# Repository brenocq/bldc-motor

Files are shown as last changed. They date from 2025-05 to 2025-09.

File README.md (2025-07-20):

<div align="center">
  
</div>

# BLDC Motor Controller

> [!NOTE]
> This project is currently in active development. Features and documentation are subject to change.

## Table of Contents
- [Project Overview](#project-overview)
- [Folder Structure](#folder-structure)
- [Mechanical](#mechanical)
- [Electronics](#electronics)
  - [MCU PCB (Top Board)](#mcu-pcb-top-board)
  - [Power PCB (Bottom Board)](#power-pcb-bottom-board)
- [Firmware](#firmware)
- [Simulation](#simulation)
- [Results](#results)
- [License](#license)

---

## Project Overview

This project aims to develop a **high-precision Brushless DC (BLDC) motor controller** from scratch, covering both hardware and firmware aspects. The controller is designed for advanced motor control applications, leveraging a powerful STM32 microcontroller, a dedicated motor driver IC, and comprehensive sensing capabilities for precise operation and rotor position estimation.

The core of the system is a custom two-board stack: an MCU board housing the main control logic and a power board managing motor drive and sensing.

## Folder Structure

The project is organized into logical directories to enhance maintainability and readability:

* `simulation/`: Contains code and files related to motor control simulation.
* `mechanical/`: Houses all mechanical design files (CAD models, part designs).
* `electronics/`: Stores KiCad project files for both the MCU and Power PCBs, including schematics and PCB layouts.
* `firmware/`: Contains all the embedded software for the STM32 microcontroller.
* `controller/`: Specific implementations of motor control algorithms (trapezoidal, FOC).
* `common/`: Shared utilities and communication definitions across different parts of the project.

---

## Mechanical

The mechanical aspects of this project are centered around integrating the custom electronics with an off-the-shelf **EM3215 BLDC motor**. It's important to note that, for this specific project, the **motor's original windings are being utilized**, and there are no plans to re-wrap the wire around the coils. The `mechanical` folder contains various CAD files (FreeCAD) for components like the rotor adapter, chassis, and PCB cutouts, ensuring a perfect fit and robust assembly.

<div align="center">
  
</div>

---

## Electronics

The electronics consist of two interconnected custom-designed Printed Circuit Boards (PCBs), designed using **KiCad**. Both boards are **4-layer designs** to facilitate efficient signal routing and power integrity. A **Molex PCB stack connector** is used to establish a robust electrical connection between the MCU and Power PCBs.

### MCU PCB (Top Board)

The top PCB serves as the brain of the controller, housing the main microcontroller and various sensors and interfaces for user interaction and precise feedback.

| Top Layer | Layer 1 | Layer 2 | Bottom Layer | 3D Top View | 3D Bottom View |
| :---: | :---: | :---: | :---: | :---: | :---: |
| Layer 1 (Top Copper) | Layer 2 (Inner 1) | Layer 3 (Inner 2) | Layer 4 (Bottom Copper) | 3D Top View | 3D Bottom View |

**MCU PCB Key Components:**
- **STM32F4 Microcontroller:** The central processing unit for control algorithms, sensor data acquisition, and communication.
- **AS5048A Angle Position Encoder:** Provides 14-bit absolute rotor position feedback for precise commutation and control.
- **SK6805 LED Ring:** A customizable visual indicator for status and debugging.
- **Reset Button:** For convenient system resets.
- **ISM330DHCX IMU (Inertial Measurement Unit):** Provides acceleration and angular velocity data, useful for advanced motion control or system stabilization.

**MCU PCB v1.0 Release Package:**
- **[KiCad Project](https://github.com/brenocq/bldc-motor/tree/electronics/v1.0/electronics/BLDCM-MCU)**
- **[Schematic (PDF)](https://github.com/brenocq/bldc-motor/blob/electronics/v1.0/electronics/BLDCM-MCU/BLDCM-MCU.pdf)**
- **[Interactive BOM (HTML)](https://brenocq.s3.us-east-1.amazonaws.com/BLDCM/BLDCM-MCU-BOM-v1.0.html)**
- **[Gerbers (ZIP)](https://github.com/brenocq/bldc-motor/releases/download/electronics%2Fv1.0/BLDCM-MCU-v1.0-gerber.zip)**

### Power PCB (Bottom Board)

The bottom PCB handles the high-current motor driving functions and essential power monitoring.

| Top Layer | Layer 1 | Layer 2 | Bottom Layer | 3D Top View | 3D Bottom View |
| :---: | :---: | :---: | :---: | :---: | :---: |
| Power PCB Layer 1 (Top Copper) | Power PCB Layer 2 (Inner 1) | Power PCB Layer 3 (Inner 2) | Power PCB Layer 4 (Bottom Copper) | Power PCB 3D Top View | Power PCB 3D Bottom View |

**Power PCB Key Components:**
- **TMC6300 Motor Driver:** A 3-phase motor driver that translates the MCU's PWM and control signals into high-current outputs for the motor phases.
- **TCAN1462 CAN Transceiver:** Enables robust CAN FD communication for daisy-chaining motors in series.
- **J-Link Connector:** Provides easy SWD debugging and programming for the STM32 microcontroller.
- **USB Connector:** Facilitates direct USB Full-Speed communication for data logging, control, and power input.
- **Micro-Lock Plus Connectors:** Robust 4-pin Molex connectors that provide a vibration-resistant link for power delivery and CAN bus communications.
- **Voltage Sensors (x4):** One monitors the DC bus voltage, while three dedicated sensors measure filtered phase voltages for safe operation and FOC.
- **INA240 Current Sensors (x3):** Three precision analog-output current sensors enable high-speed, accurate phase current measurement for FOC.

**Power PCB v1.0 Release Package:**
- **[KiCad Project](https://github.com/brenocq/bldc-motor/tree/electronics/v1.0/electronics/BLDCM-Power)**
- **[Schematic (PDF)](https://github.com/brenocq/bldc-motor/blob/electronics/v1.0/electronics/BLDCM-Power/BLDCM-Power.pdf)**
- **[Interactive BOM (HTML)](https://brenocq.s3.us-east-1.amazonaws.com/BLDCM/BLDCM-Power-BOM-v1.0.html)**
- **[Gerbers (ZIP)](https://github.com/brenocq/bldc-motor/releases/download/electronics%2Fv1.0/BLDCM-Power-v1.0-gerber.zip)**

---

## Firmware

The firmware, developed for the **STM32F4** microcontroller, is the intelligence behind the motor control. It includes:

* **Low-level Peripheral Drivers:** Custom drivers for ADC, timers, GPIO, SPI, I2C, UART, USB, and DMA to efficiently manage hardware resources.
* **Motor Control Algorithms:** Implementation of both **trapezoidal** and **Field-Oriented Control (FOC)** algorithms, located in the `controller` directory, to provide flexible and high-performance motor driving capabilities.
* **Sensor Integration:** Code to interface with the MT6701 encoder, INA239-Q1 current sensors, voltage sensor, and ISM330DHCX IMU for comprehensive feedback.
* **System Utilities:** Logging, error handling, and platform-specific configurations for the STM32 environment.

_The firmware architecture and design decisions will be documented in the future._

---

## Simulation

The `simulation` directory contains resources for simulating the BLDC motor system and visualizing the sensor data in real time. This allows for testing and validating control algorithms and system behavior in a virtual environment before deployment on the hardware. The `bldc.atta` file can be opened with [Atta](https://github.com/brenocq/atta), and it implements a basic motor model simulation and plotting of sensor data.

_Instructions on how to run the BLDCM simulation with [Atta](https://github.com/brenocq/atta) will be added in the future_

---

## Results

Below are some pictures/videos taken during the development. The controller design and calibration procedures will be explained in depth in the future :)

https://github.com/user-attachments/assets/e86b0316-7ecf-4e15-9d3b-c0315d690438

<div align="center">
  
  
  
</div>

## License
This project is licensed under the MIT License - check [LICENSE](LICENSE) for details.

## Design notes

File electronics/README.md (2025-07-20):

# BLDCM Electronics
These KiCad projects were made with KiCad 9.0, make sure to use the same version or a newer one.

The schematic PDFs are available in `BLDCM-Power/BLDCM-Power.pdf` and `BLDCM-MCU/BLDCM-MCU.pdf`. The Gerber files and interactive BOM can be found in the release section of the repository.

> [!IMPORTANT]
> This project depends on the [BrenoCQ KiCad library](https://github.com/brenocq/brenocq-kicad-library), included as a Git submodule. To ensure all symbols, footprints, and 3D models are available, you must initialize the submodules:
>
> ```bash
> git submodule update --init --recursive
> ```

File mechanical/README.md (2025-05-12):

# BLDC Motor - Mechanical

The 3D models were designed using FreeCAD 1.0.0, Git Large File Storage (LFS) was enabled so we can store the `.FCStd` files in this repository without considerably growing the repository size.

### BOM
- Three-phase motor OT-EM3215D2450Y1R - [Sparkfun](https://www.sparkfun.com/three-phase-brushless-gimbal-stabilizer-motor.html)

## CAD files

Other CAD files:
mechanical/BLDCM.FCStd
mechanical/BLDCM_Chassis.FCStd
mechanical/BLDCM_PCB_MCU.FCStd
mechanical/BLDCM_Rotor_Adapter.FCStd
mechanical/parts/Motor_EM3215.FCStd
mechanical/BLDCM_PCB_Power.FCStd
mechanical/parts/Test_HeatSet_Hole.FCStd
mechanical/parts/HeatSet_M1.6_3MM.FCStd
mechanical/parts/Screw_CS_5MM.FCStd
mechanical/parts/Flat_Washer_M1.6.FCStd
mechanical/parts/Screw_P_8MM.FCStd

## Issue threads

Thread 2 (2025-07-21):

[Bug] v1.0 PCB Issues & Revisions

brenocq, 2025-07-21:
**Overview**
This issue serves as a master list to track all identified bugs, design flaws, and potential improvements for the [v1.0 MCU and Power PCBs](https://github.com/brenocq/bldc-motor/releases/tag/electronics%2Fv1.0). The goal is to consolidate all feedback from testing and board bring-up to inform the design of the v1.1 revision.

brenocq, 2025-08-02:
It would be better to cover vias with solder mask if they are close to pads of different nets (to avoid solder bridges between different nets)

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

brenocq, 2025-08-05:
## BLDCM-MCU v1.0 bring-up checklist
- [x] Solder all components
- [x] Visual inspection (solder bridges, alignment)
- [ ] Verify orientation of all ICs
- [ ] Clean board with IPA
- [ ] Continuity check for all adjacent pins
- [ ] Check resistance between all power rails (3.3V, 5V) and GND
- [ ] Apply current-limited Power @ 50mA
- [ ] Verify 3.3V power rail
- [ ] Connect ST-Link and verify MCU detection
- [ ] Flash simple firmware

brenocq, 2025-08-16:
## Firmware v1.0 bring-up checklist
- [ ] Finalize pinout assignments
- [ ] Establish real-time logging via SWO
- [ ] Test UART interface
- [ ] Verify the TMC6300 motor driver functionality.
- [ ] Implement and test USB interface
- [ ] Validate INA240A1 current measurements
- [ ] Validate voltage measurements
- [ ] Verify data acquisition from the ISM330DHCX IMU
- [ ] Implement and validate the AS5048A encoder driver
- [ ] Validate the SK6805 RGB LED driver

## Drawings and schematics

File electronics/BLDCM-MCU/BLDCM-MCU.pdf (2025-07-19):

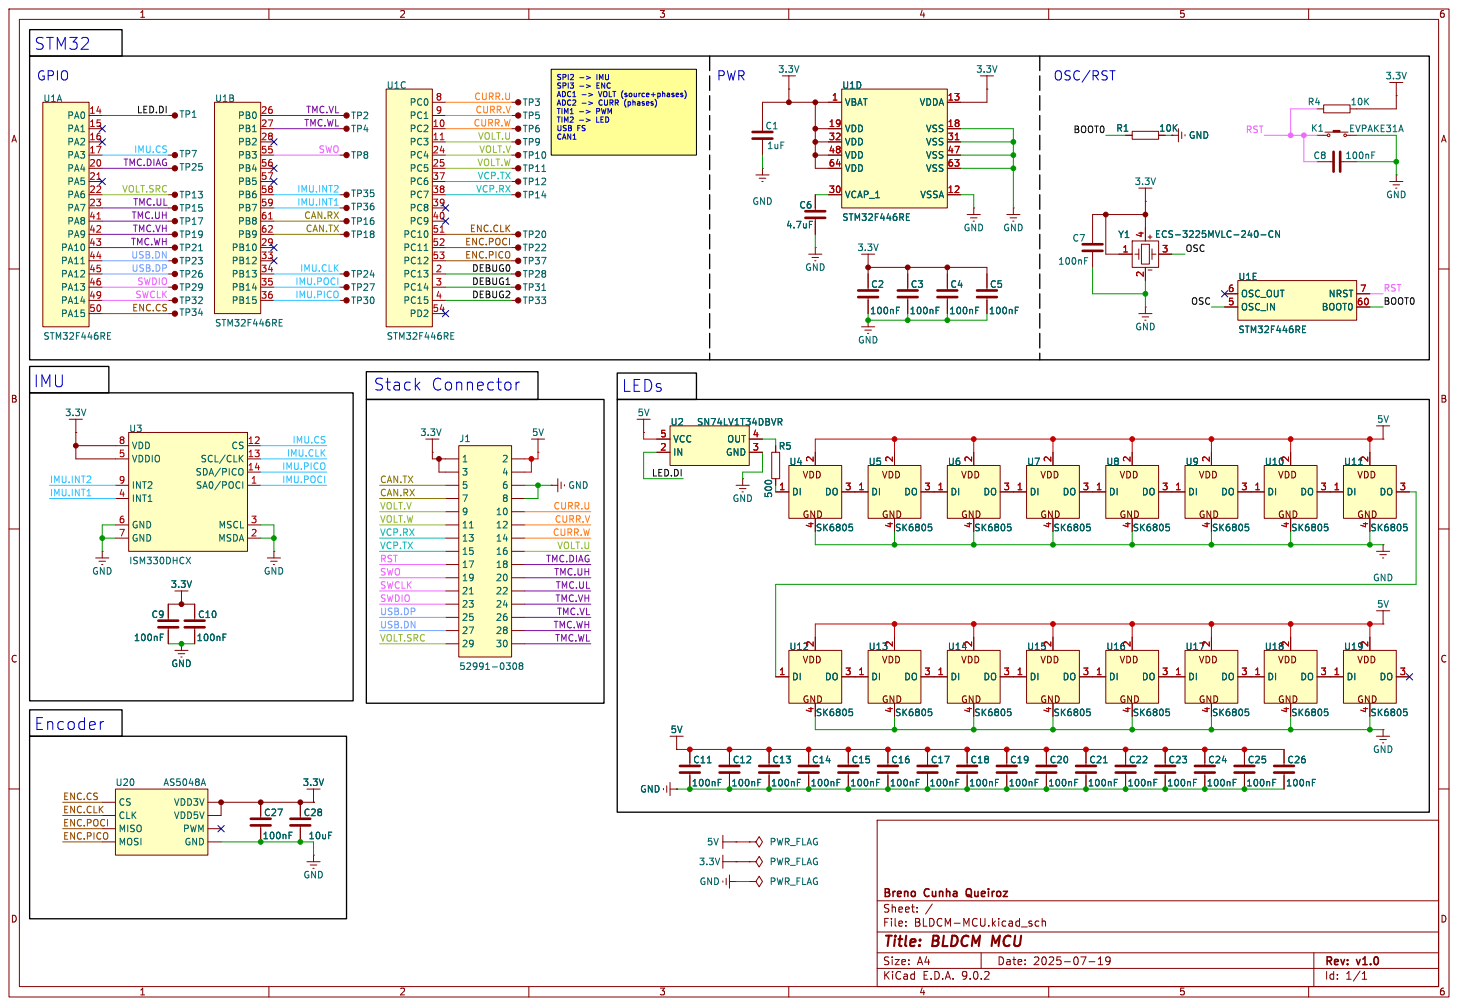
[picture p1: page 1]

USB FS CAN1 Stack Connector

VOLT.SRC
TMC.UH
TMC.VH
DEBUG2 TMC.WH
USB.DN
RST BOOT0 ENC.CS USB.DP
SWDIO

IMU.INT1
ENC.POCI CAN.RX
DEBUG0 DEBUG1 CAN.TX

CAN.TX RST CAN.RX

TMC.WL TMC.WH

File: BLDCM-MCU.kicad_sch Sheet: / Breno Cunha Queiroz

Id: 1/1 Title: BLDCM MCU

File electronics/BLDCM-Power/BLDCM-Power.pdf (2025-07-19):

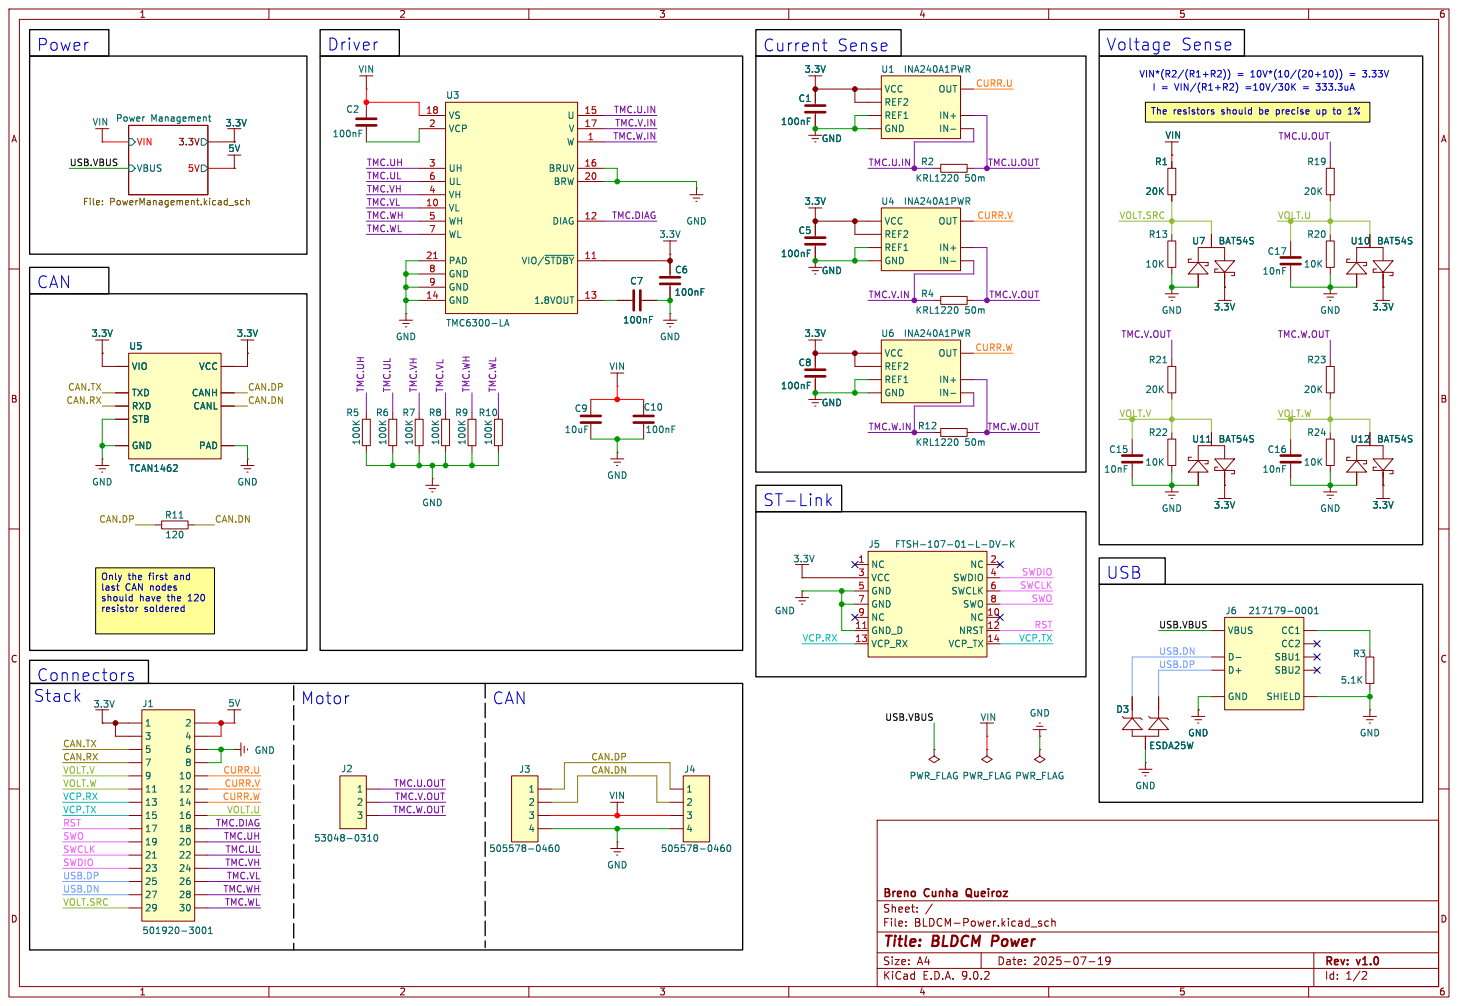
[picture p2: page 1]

TMC.UL TMC.VL TMC.VH
TMC.VH

TMC.WL TMC.WH

CAN.DP CAN.DN

Only the first and
last CAN nodes
should have the 120

USB.VBUS USB.DP USB.DN

Stack
CAN.RX CAN.TX USB.DP

Id: 1/2 Title: BLDCM Power File: BLDCM-Power.kicad_sch Sheet: / Breno Cunha Queiroz

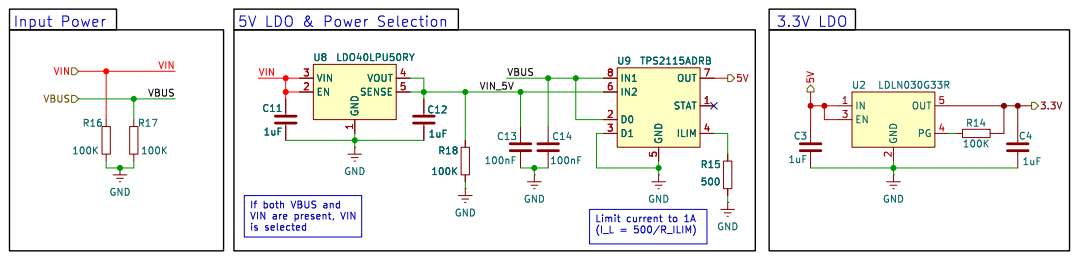
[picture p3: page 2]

If both VBUS and VIN are present, VIN

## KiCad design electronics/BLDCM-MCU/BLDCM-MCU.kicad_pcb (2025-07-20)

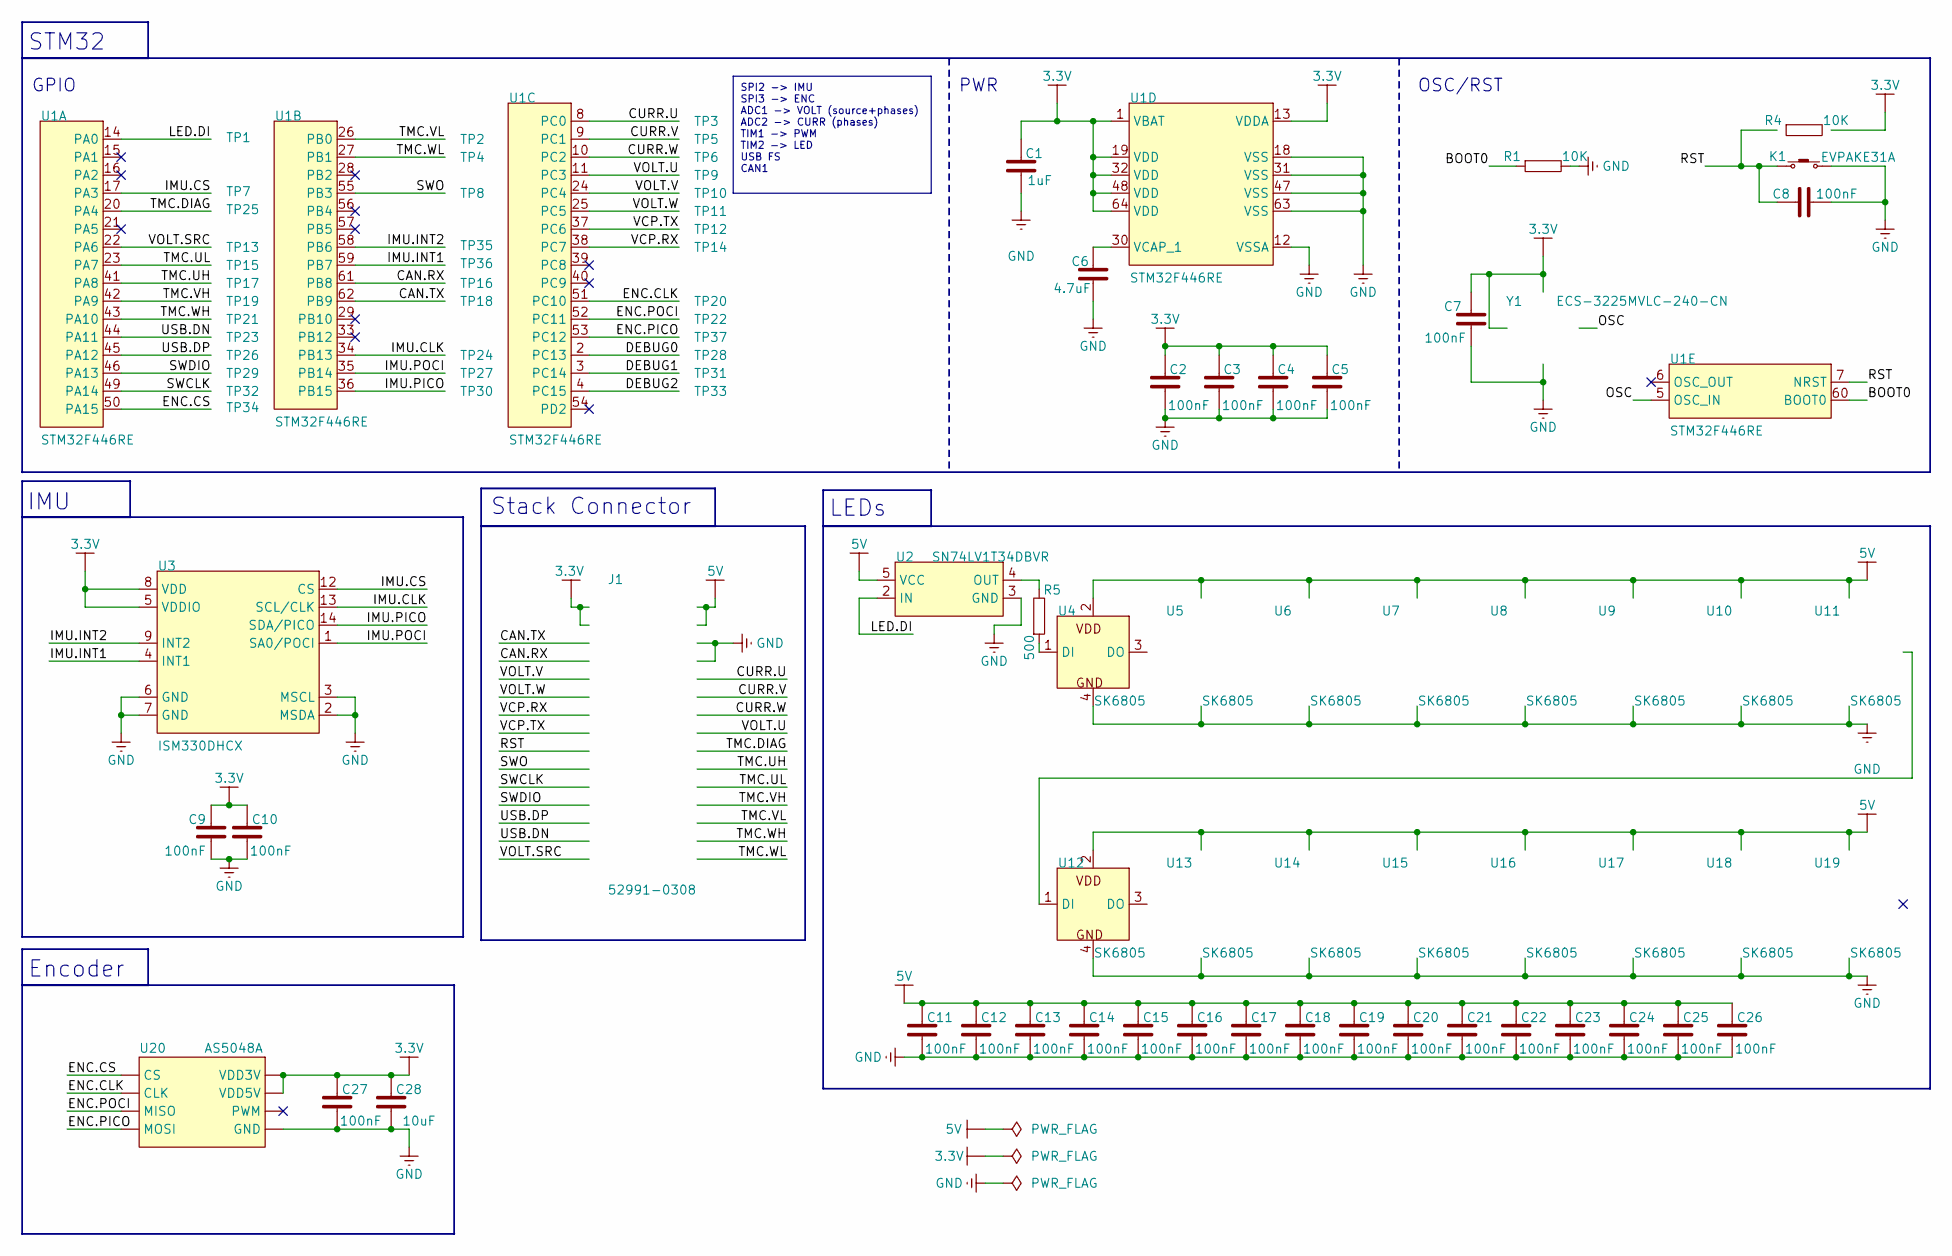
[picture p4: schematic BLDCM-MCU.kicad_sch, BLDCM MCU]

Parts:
C1: 1uF; C_0402
C2, C3, C4, C5, C7, C8, C9, C10, C11, C12, C13, C14, C15, C16, C17, C18, C19, C20, C21, C22, C23, C24, C25, C26, C27: 100nF; C_0402
C6: 4.7uF; C_0603
C28: 10uF; C_0805
J1: 52991-0308
K1: EVPAKE31A
R1, R4: 10K; R_0402
R5: 500; R_0402
TP1, TP2, TP3, TP4, TP5, TP6, TP7, TP8, TP9, TP10, TP11, TP12, TP13, TP14, TP15, TP16, TP17, TP18, TP19, TP20, TP21, TP22, TP23, TP24, TP25, TP26, TP27, TP28, TP29, TP30, TP31, TP32, TP33, TP34, TP35, TP36, TP37: Test point 0.5mm; TP_0.5mm
U1: STM32F446RE; LQFP64
U2: SN74LV1T34DBVR; SOT-23-5
U3: ISM330DHCX; LGA-14L
U4, U5, U6, U7, U8, U9, U10, U11, U12, U13, U14, U15, U16, U17, U18, U19: SK6805; LED-1515
U20: AS5048A; TSSOP-14
Y1: ECS-3225MVLC-240-CN; Crystal_3225

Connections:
3.3V: C1.2, C2.2, C3.2, C4.2, C5.2, C7.2, C9.2, C10.2, C27.2, C28.2, J1.1, J1.3, R4.2, U1.1 (VBAT), U1.13 (VDDA), U1.19 (VDD), U1.32 (VDD), U1.48 (VDD), U1.64 (VDD), U3.5 (VDDIO), U3.8 (VDD), U20.11 (VDD5V), U20.12 (VDD3V), Y1.1, Y1.4
5V: C11.2, C12.2, C13.2, C14.2, C15.2, C16.2, C17.2, C18.2, C19.2, C20.2, C21.2, C22.2, C23.2, C24.2, C25.2, C26.2, J1.2, J1.4, U2.5 (VCC), U4.2 (VDD), U5.2 (VDD), U6.2 (VDD), U7.2 (VDD), U8.2 (VDD), U9.2 (VDD), U10.2 (VDD), U11.2 (VDD), U12.2 (VDD), U13.2 (VDD), U14.2 (VDD), U15.2 (VDD), U16.2 (VDD), U17.2 (VDD), U18.2 (VDD), U19.2 (VDD)
/BOOT0: R1.1, U1.60 (BOOT0)
/CAN.RX: J1.7, TP16.1, U1.61 (PB8)
/CAN.TX: J1.5, TP18.1, U1.62 (PB9)
/CURR.U: J1.10, TP3.1, U1.8 (PC0)
/CURR.V: J1.12, TP5.1, U1.9 (PC1)
/CURR.W: J1.14, TP6.1, U1.10 (PC2)
/DEBUG0: TP28.1, U1.2 (PC13)
/DEBUG1: TP31.1, U1.3 (PC14)
/DEBUG2: TP33.1, U1.4 (PC15)
/ENC.CLK: TP20.1, U1.51 (PC10), U20.2 (CLK)
/ENC.CS: TP34.1, U1.50 (PA15), U20.1 (CS)
/ENC.PICO: TP37.1, U1.53 (PC12), U20.4 (MOSI)
/ENC.POCI: TP22.1, U1.52 (PC11), U20.3 (MISO)
/IMU.CLK: TP24.1, U1.34 (PB13), U3.13 (SCL/CLK)
/IMU.CS: TP7.1, U1.17 (PA3), U3.12 (CS)
/IMU.INT1: TP36.1, U1.59 (PB7), U3.4 (INT1)
/IMU.INT2: TP35.1, U1.58 (PB6), U3.9 (INT2)
/IMU.PICO: TP30.1, U1.36 (PB15), U3.14 (SDA/PICO)
/IMU.POCI: TP27.1, U1.35 (PB14), U3.1 (SA0/POCI)
/LED.DI: TP1.1, U1.14 (PA0), U2.2 (IN)
/OSC: U1.5 (OSC_IN), Y1.3
/RST: C8.2, J1.17, K1.1, R4.1, U1.7 (NRST)
/SWCLK: J1.21, TP32.1, U1.49 (PA14)
/SWDIO: J1.23, TP29.1, U1.46 (PA13)
/SWO: J1.19, TP8.1, U1.55 (PB3)
/TMC.DIAG: J1.18, TP25.1, U1.20 (PA4)
/TMC.UH: J1.20, TP17.1, U1.41 (PA8)
/TMC.UL: J1.22, TP15.1, U1.23 (PA7)
/TMC.VH: J1.24, TP19.1, U1.42 (PA9)
/TMC.VL: J1.26, TP2.1, U1.26 (PB0)
/TMC.WH: J1.28, TP21.1, U1.43 (PA10)
/TMC.WL: J1.30, TP4.1, U1.27 (PB1)
/USB.DN: J1.27, TP23.1, U1.44 (PA11)
/USB.DP: J1.25, TP26.1, U1.45 (PA12)
/VCP.RX: J1.13, TP14.1, U1.38 (PC7)
/VCP.TX: J1.15, TP12.1, U1.37 (PC6)
/VOLT.SRC: J1.29, TP13.1, U1.22 (PA6)
/VOLT.U: J1.16, TP9.1, U1.11 (PC3)
/VOLT.V: J1.9, TP10.1, U1.24 (PC4)
/VOLT.W: J1.11, TP11.1, U1.25 (PC5)
GND: C1.1, C2.1, C3.1, C4.1, C5.1, C6.1, C7.1, C8.1, C9.1, C10.1, C11.1, C12.1, C13.1, C14.1, C15.1, C16.1, C17.1, C18.1, C19.1, C20.1, C21.1, C22.1, C23.1, C24.1, C25.1, C26.1, C27.1, C28.1, J1.6, J1.8, K1.2, R1.2, U1.12 (VSSA), U1.18 (VSS), U1.31 (VSS), U1.47 (VSS), U1.63 (VSS), U2.3 (GND), U3.2 (MSDA), U3.3 (MSCL), U3.6 (GND), U3.7 (GND), U4.4 (GND), U5.4 (GND), U6.4 (GND), U7.4 (GND), U8.4 (GND), U9.4 (GND), U10.4 (GND), U11.4 (GND), U12.4 (GND), U13.4 (GND), U14.4 (GND), U15.4 (GND), U16.4 (GND), U17.4 (GND), U18.4 (GND), U19.4 (GND), U20.13 (GND), Y1.2
unnamed: C6.2, U1.30 (VCAP_1)
unnamed: R5.2, U2.4 (OUT)
unnamed: R5.1, U4.1 (DI)
unnamed: U4.3 (DO), U5.1 (DI)
unnamed: U5.3 (DO), U6.1 (DI)
unnamed: U6.3 (DO), U7.1 (DI)
unnamed: U7.3 (DO), U8.1 (DI)
unnamed: U8.3 (DO), U9.1 (DI)
unnamed: U9.3 (DO), U10.1 (DI)
unnamed: U10.3 (DO), U11.1 (DI)
unnamed: U11.3 (DO), U12.1 (DI)
unnamed: U12.3 (DO), U13.1 (DI)
unnamed: U13.3 (DO), U14.1 (DI)
unnamed: U14.3 (DO), U15.1 (DI)
unnamed: U15.3 (DO), U16.1 (DI)
unnamed: U16.3 (DO), U17.1 (DI)
unnamed: U17.3 (DO), U18.1 (DI)
unnamed: U18.3 (DO), U19.1 (DI)

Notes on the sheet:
STM32
IMU
LEDs
Stack Connector
Encoder
OSC/RST
GPIO
PWR
SPI2 -> IMU SPI3 -> ENC ADC1 -> VOLT (source+phases) ADC2 -> CURR (phases) TIM1 -> PWM TIM2 -> LED USB FS CAN1

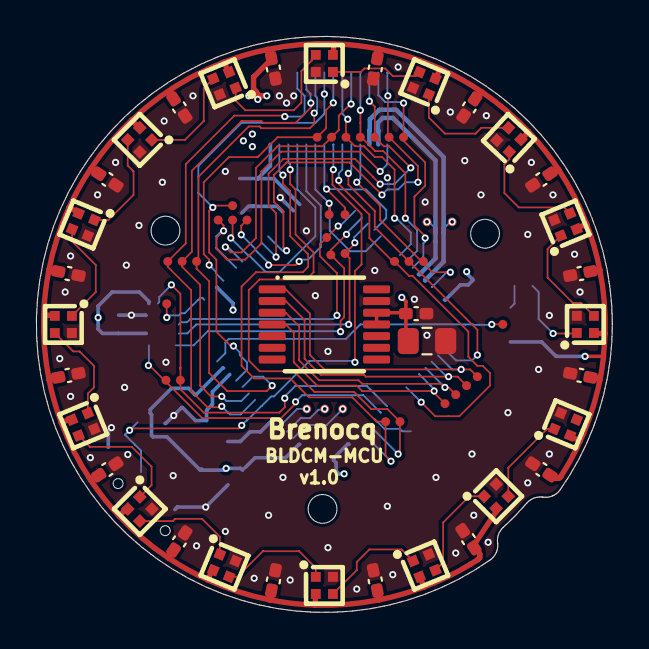
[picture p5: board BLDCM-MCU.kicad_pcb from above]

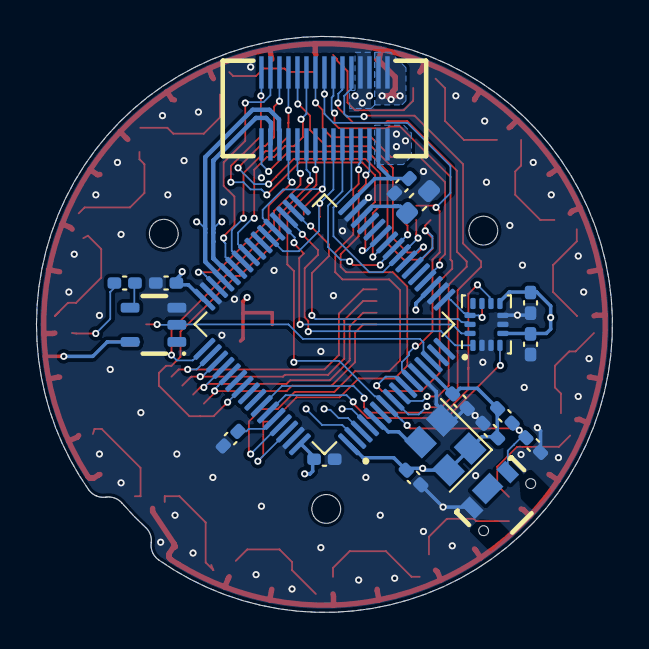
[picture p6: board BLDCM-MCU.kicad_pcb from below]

Board: 4 copper layers, 32.0 x 32.0 mm, 91 parts (19 on the bottom side), 61 nets.

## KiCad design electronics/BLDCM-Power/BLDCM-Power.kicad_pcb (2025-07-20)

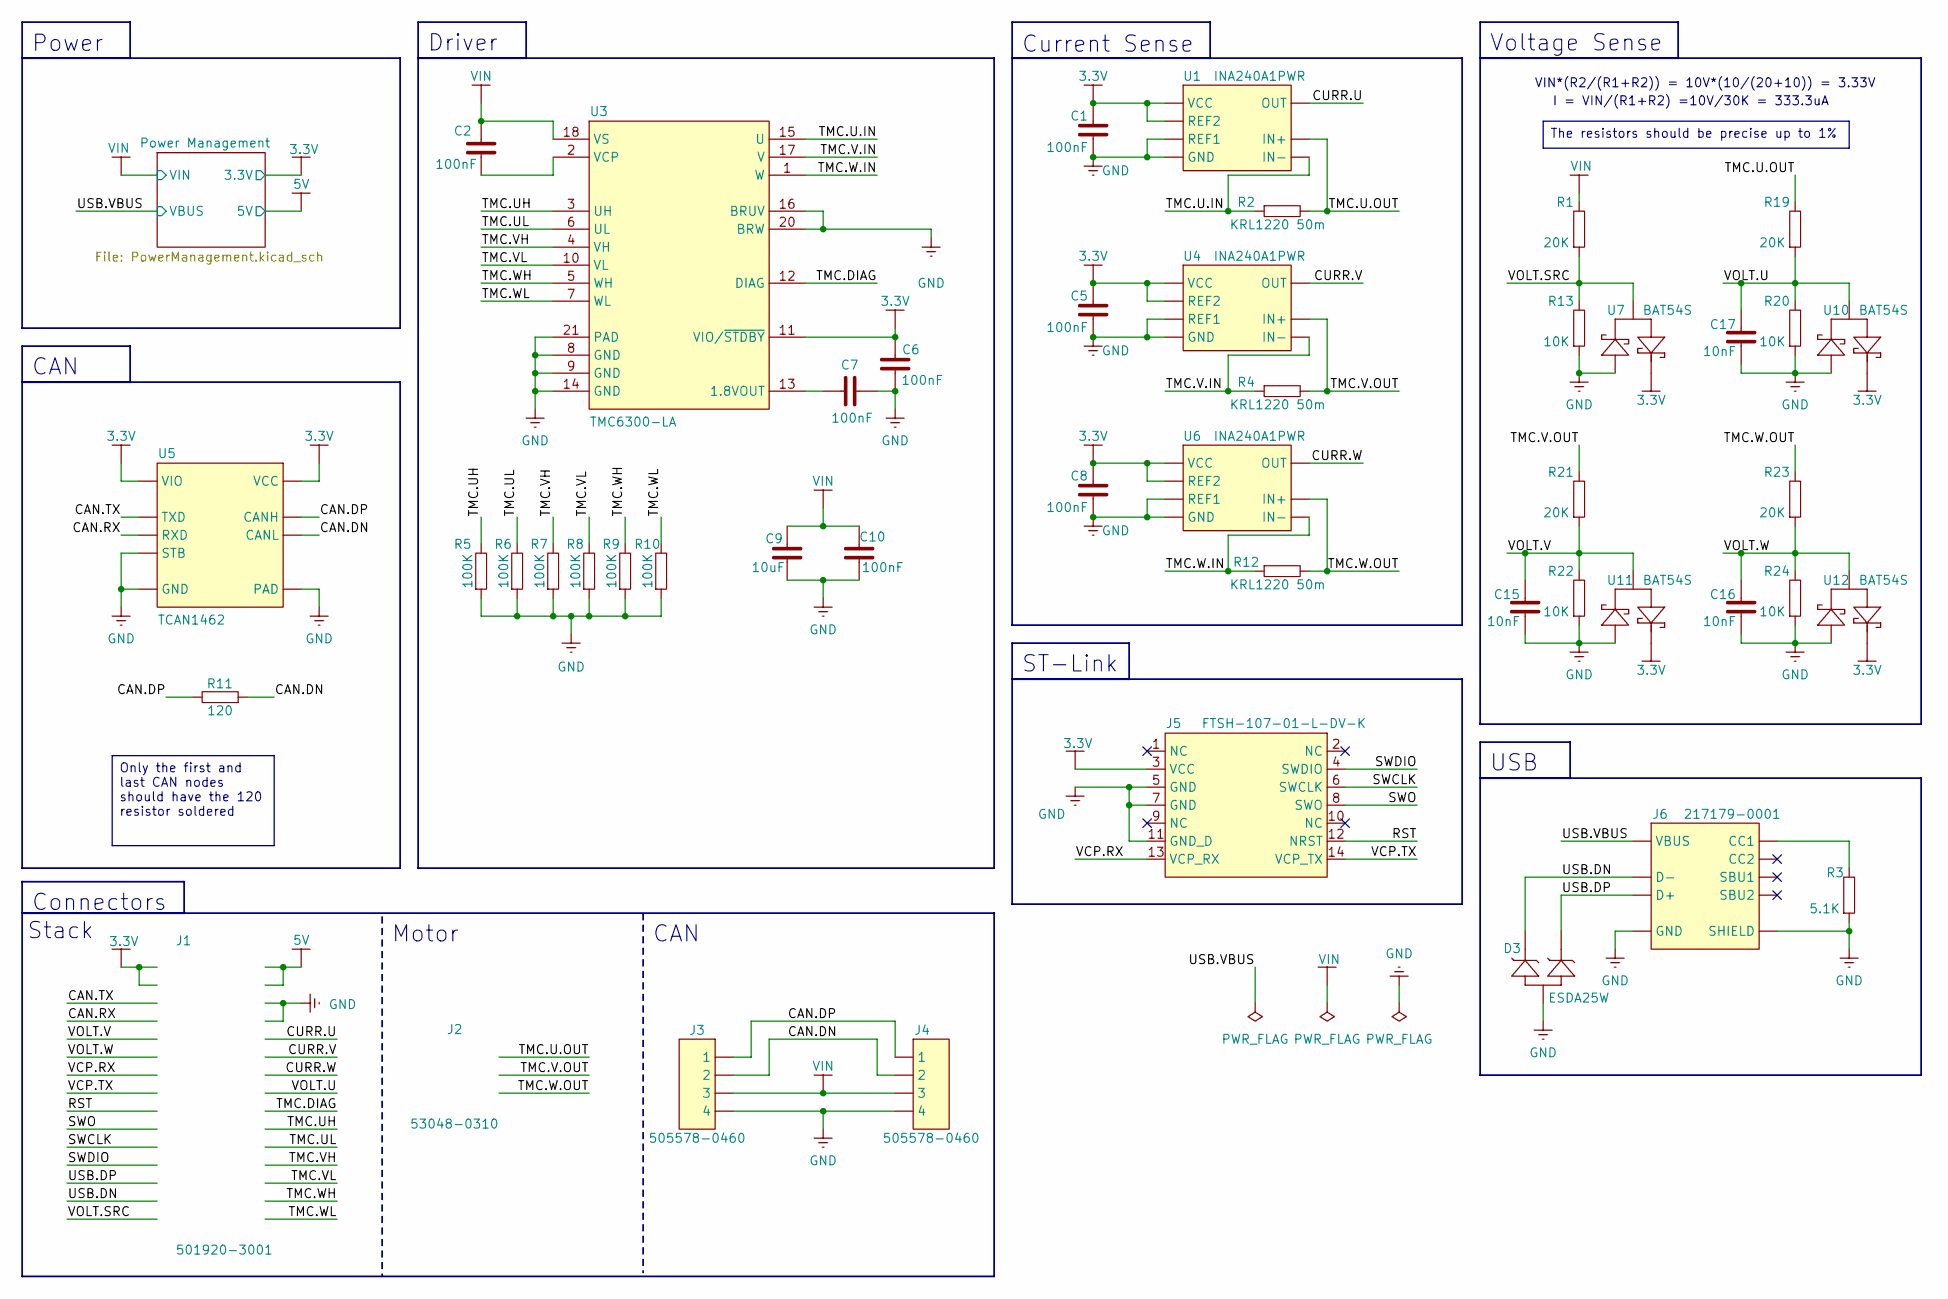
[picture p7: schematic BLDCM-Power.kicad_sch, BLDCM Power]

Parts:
C1, C2, C5, C6, C7, C8, C10: 100nF; C_0402
C9: 10uF; C_0805
C15, C16, C17: 10nF; C_0402
D3: ESDA25W; SOT-323
J1: 501920-3001
J2: 53048-0310
J3, J4: 505578-0460
J5: FTSH-107-01-L-DV-K; FTSH-107-01-L-DV-K-TR
J6: 217179-0001
R1, R19, R21, R23: 20K; R_0402
R2, R4, R12: KRL1220 50m; KRL1220
R3: 5.1K; R_0402
R5, R6, R7, R8, R9, R10: 100K; R_0402
R11: 120; R_0402
R13, R20, R22, R24: 10K; R_0402
U1, U4, U6: INA240A1PWR; TSSOP-8
U3: TMC6300-LA; QFN-20
U5: TCAN1462; VSON-8
U7, U10, U11, U12: BAT54S; SOT-23

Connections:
3.3V: C1.1, C5.1, C6.2, C8.1, J1.1, J1.3, J5.3 (VCC), U1.5 (VCC), U1.6 (REF2), U3.11 (VIO/~STDBY), U4.5 (VCC), U4.6 (REF2), U5.3 (VCC), U5.5 (VIO), U6.5 (VCC), U6.6 (REF2), U7.2, U10.2, U11.2, U12.2; also elsewhere on the board
5V: J1.2, J1.4; also elsewhere on the board
/CAN.DN: J3.2, J4.2, R11.1, U5.6 (CANL)
/CAN.DP: J3.1, J4.1, R11.2, U5.7 (CANH)
/CAN.RX: J1.7, U5.4 (RXD)
/CAN.TX: J1.5, U5.1 (TXD)
/CURR.U: J1.10, U1.8 (OUT)
/CURR.V: J1.12, U4.8 (OUT)
/CURR.W: J1.14, U6.8 (OUT)
/RST: J1.17, J5.12 (NRST)
/SWCLK: J1.21, J5.6 (SWCLK)
/SWDIO: J1.23, J5.4 (SWDIO)
/SWO: J1.19, J5.8 (SWO)
/TMC.DIAG: J1.18, U3.12 (DIAG)
/TMC.U.IN: R2.1, U1.3 (IN-), U3.15 (U)
/TMC.U.OUT: J2.1, R2.2, R19.2, U1.2 (IN+)
/TMC.UH: J1.20, R5.2, U3.3 (UH)
/TMC.UL: J1.22, R6.2, U3.6 (UL)
/TMC.V.IN: R4.1, U3.17 (V), U4.3 (IN-)
/TMC.V.OUT: J2.2, R4.2, R21.2, U4.2 (IN+)
/TMC.VH: J1.24, R7.2, U3.4 (VH)
/TMC.VL: J1.26, R8.2, U3.10 (VL)
/TMC.W.IN: R12.1, U3.1 (W), U6.3 (IN-)
/TMC.W.OUT: J2.3, R12.2, R23.2, U6.2 (IN+)
/TMC.WH: J1.28, R9.2, U3.5 (WH)
/TMC.WL: J1.30, R10.2, U3.7 (WL)
/USB.DN: D3.1, J1.27, J6.A7 (D-), J6.B7 (D-2)
/USB.DP: D3.2, J1.25, J6.A6 (D+), J6.B6 (D+2)
/VCP.RX: J1.13, J5.13 (VCP_RX)
/VCP.TX: J1.15, J5.14 (VCP_TX)
/VOLT.SRC: J1.29, R1.1, R13.2, U7.3
/VOLT.U: C17.2, J1.16, R19.1, R20.2, U10.3
/VOLT.V: C15.2, J1.9, R21.1, R22.2, U11.3
/VOLT.W: C16.2, J1.11, R23.1, R24.2, U12.3
GND: C1.2, C5.2, C6.1, C7.1, C8.2, C9.1, C10.1, C15.1, C16.1, C17.1, D3.3, J1.6, J1.8, J3.4, J4.4, J5.5 (GND), J5.7 (GND), J5.11 (GND_D), J6.A1_B12 (GND), J6.B1_A12 (GND), J6.SH1 (SHIELD), J6.SH2 (SHIELD), J6.SH3 (SHIELD), J6.SH4 (SHIELD), R3.1, R5.1, R6.1, R7.1, R8.1, R9.1, R10.1, R13.1, R20.1, R22.1, R24.1, U1.4 (GND), U1.7 (REF1), U3.8 (GND), U3.9 (GND), U3.14 (GND), U3.16 (BRUV), U3.20 (BRW), U3.21 (PAD), U4.4 (GND), U4.7 (REF1), U5.2 (GND), U5.8 (STB), U5.PAD, U6.4 (GND), U6.7 (REF1), U7.1, U10.1, U11.1, U12.1; also elsewhere on the board
unnamed: J6.A5 (CC1), R3.2
unnamed: C7.2, U3.13 (1.8VOUT)
unnamed: C2.1, U3.2 (VCP)
VBUS: J6.A4_B9 (VBUS), J6.B4_A9 (VBUS); also elsewhere on the board
VIN: C2.2, C9.2, C10.2, J3.3, J4.3, R1.2, U3.18 (VS); also elsewhere on the board

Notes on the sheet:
ST-Link
I = VIN/(R1+R2) =10V/30K = 333.3uA
Driver
Stack
Power
CAN
VIN*(R2/(R1+R2)) = 10V*(10/(20+10)) = 3.33V
Motor
Voltage Sense
USB
Connectors
Current Sense
The resistors should be precise up to 1%
Only the first and last CAN nodes should have the 120 resistor soldered

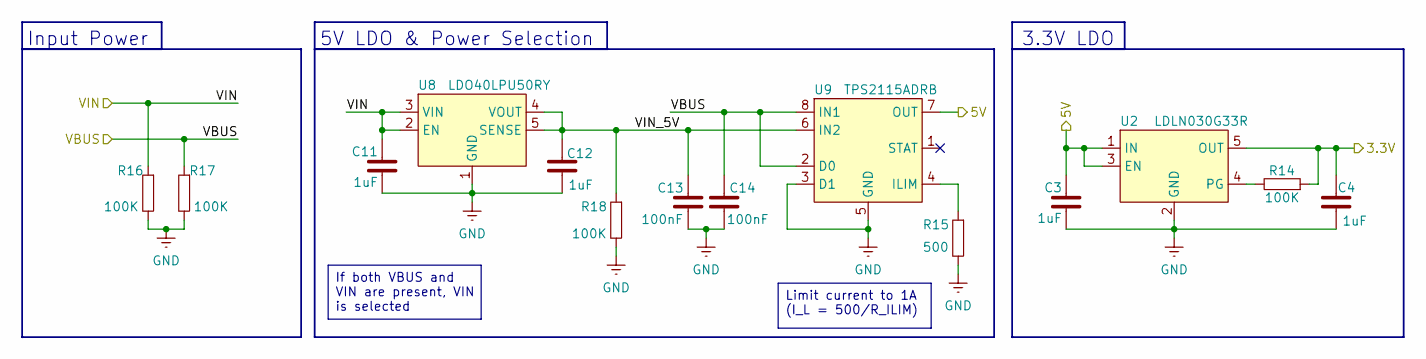
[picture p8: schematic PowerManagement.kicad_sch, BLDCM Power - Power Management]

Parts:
C3, C4, C11, C12: 1uF; C_0402
C13, C14: 100nF; C_0402
R14, R16, R17, R18: 100K; R_0402
R15: 500; R_0402
U2: LDLN030G33R; TSOT-23-5
U8: LDO40LPU50RY; DFN-6-3x3
U9: TPS2115ADRB; VSON-8

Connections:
3.3V: C4.2, R14.1, U2.5 (OUT); also elsewhere on the board
5V: C3.2, U2.1 (IN), U2.3 (EN), U9.7 (OUT); also elsewhere on the board
/Power Management/VIN_5V: C12.2, C13.1, R18.1, U8.4 (VOUT), U8.5 (SENSE), U9.6 (IN2)
GND: C3.1, C4.1, C11.1, C12.1, C13.2, C14.2, R15.2, R16.2, R17.2, R18.2, U2.2 (GND), U8.1 (GND), U8.PAD, U9.3 (D1), U9.5 (GND), U9.PAD; also elsewhere on the board
unnamed: R14.2, U2.4 (PG)
unnamed: R15.1, U9.4 (ILIM)
VBUS: C14.1, R17.1, U9.2 (D0), U9.8 (IN1); also elsewhere on the board
VIN: C11.2, R16.1, U8.2 (EN), U8.3 (VIN); also elsewhere on the board

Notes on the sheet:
Input Power
3.3V LDO
5V LDO & Power Selection
Limit current to 1A (I_L = 500/R_ILIM)
If both VBUS and VIN are present, VIN is selected

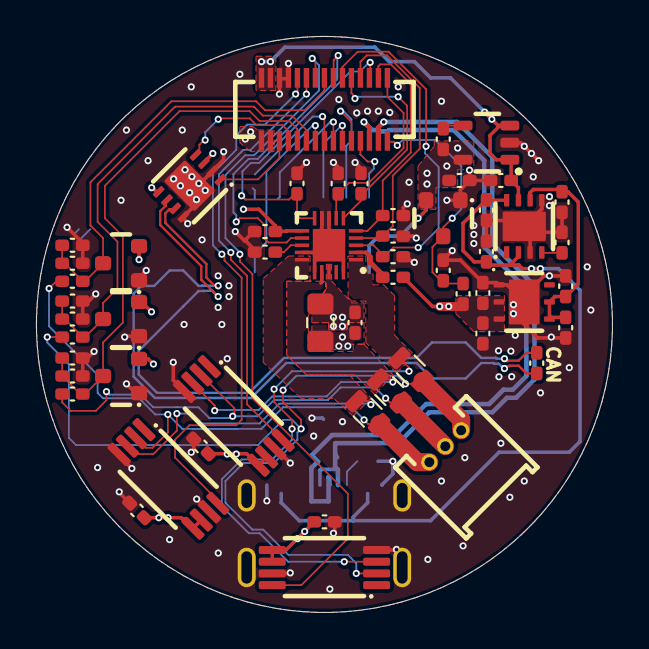
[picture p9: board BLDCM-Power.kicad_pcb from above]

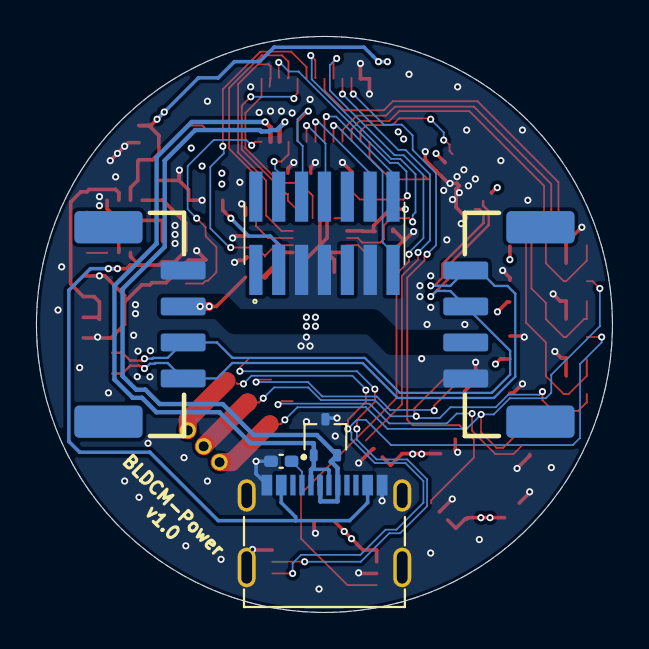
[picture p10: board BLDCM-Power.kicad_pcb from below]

Board: 4 copper layers, 32.0 x 32.0 mm, 60 parts (6 on the bottom side), 43 nets.

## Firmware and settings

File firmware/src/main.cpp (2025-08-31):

//--------------------------------------------------
// BLDC Motor Controller
// main.cpp
// Date: 2023-09-07
// By Breno Cunha Queiroz
//--------------------------------------------------
#include <drivers/hardware.h>
#include <utils/error.h>
#include <utils/log.h>

// FreeRTOS includes
#include <FreeRTOS.h>
#include <cmsis_os.h>
#include <tasks/tasks.h>

int main() {
    // Initialize hardware peripherals and drivers
    if (!Hardware::init())
        Error::hardFault("Failed to initialize hardware!");
    else
        Log::success("Main", "Hardware initialized");

    // Initialize FreeRTOS and tasks
    osKernelInitialize();
    if (!Tasks::init())
        Error::hardFault("Failed to initialize tasks!");
    osKernelStart();

    while (true) {
        // ...
    }
    return 0;
}

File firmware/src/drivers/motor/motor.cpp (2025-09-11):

//--------------------------------------------------
// BLDC Motor Controller
// motor.cpp
// Date: 2023-09-18
// By Breno Cunha Queiroz
//--------------------------------------------------
#include <drivers/hardware.h>
#include <drivers/motor/motor.h>
#include <drivers/timer/timer.h>
#include <utils/log.h>

bool Motor::init() {
    setPwm(Timer::MOTOR_TIM, Timer::MOTOR_CH_U, 0);
    setPwm(Timer::MOTOR_TIM, Timer::MOTOR_CH_V, 0);
    setPwm(Timer::MOTOR_TIM, Timer::MOTOR_CH_W, 0);
    startPwm(Timer::MOTOR_TIM, Timer::MOTOR_CH_U);
    startPwm(Timer::MOTOR_TIM, Timer::MOTOR_CH_V);
    startPwm(Timer::MOTOR_TIM, Timer::MOTOR_CH_W);
    return true;
}

void Motor::set(float angle, float magnitude) {
    // Sector from the space vector diagram
    int sector = static_cast<int>(angle / (M_PI / 3));

    // Calculate ratios
    float sectorAngle = angle - sector * (M_PI / 3);
    float t1 = magnitude * std::sin(M_PI / 3 - sectorAngle); // Time ratio first vector from sector
    float t2 = magnitude * std::sin(sectorAngle);            // Time ratio second vector from sector
    float t0 = 1.0 - t1 - t2;                                // Time ratio null vector

    // Calculate channel CCR for each phase
    constexpr uint16_t maxPeriod = Timer::MOTOR_PERIOD;
    uint16_t uPeriod = maxPeriod;
    uint16_t vPeriod = maxPeriod;
    uint16_t wPeriod = maxPeriod;

    switch (sector) {
        case 0:
            uPeriod -= (t0 / 2) * maxPeriod;
            vPeriod -= ((t0 / 2) + t1) * maxPeriod;
            wPeriod -= ((t0 / 2) + t1 + t2) * maxPeriod;
            break;
        case 1:
            uPeriod -= ((t0 / 2) + t2) * maxPeriod;
            vPeriod -= (t0 / 2) * maxPeriod;
            wPeriod -= ((t0 / 2) + t1 + t2) * maxPeriod;
            break;
        case 2:
            uPeriod -= ((t0 / 2) + t1 + t2) * maxPeriod;
            vPeriod -= (t0 / 2) * maxPeriod;
            wPeriod -= ((t0 / 2) + t1) * maxPeriod;
            break;
        case 3:
            uPeriod -= ((t0 / 2) + t1 + t2) * maxPeriod;
            vPeriod -= ((t0 / 2) + t2) * maxPeriod;
            wPeriod -= (t0 / 2) * maxPeriod;
            break;
        case 4:
            uPeriod -= ((t0 / 2) + t1) * maxPeriod;
            vPeriod -= ((t0 / 2) + t1 + t2) * maxPeriod;
            wPeriod -= (t0 / 2) * maxPeriod;
            break;
        case 5:
            uPeriod -= (t0 / 2) * maxPeriod;
            vPeriod -= ((t0 / 2) + t1 + t2) * maxPeriod;
            wPeriod -= ((t0 / 2) + t2) * maxPeriod;
            break;
        default:
            Log::error("Motor", "Invalid section");
            return;
    }

    Timer::setPwm(Timer::MOTOR_TIM, Timer::MOTOR_CH_U, uPeriod);
    Timer::setPwm(Timer::MOTOR_TIM, Timer::MOTOR_CH_V, vPeriod);
    Timer::setPwm(Timer::MOTOR_TIM, Timer::MOTOR_CH_W, wPeriod);
}

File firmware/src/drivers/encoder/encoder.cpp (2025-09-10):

//--------------------------------------------------
// BLDC Motor Controller
// encoder.cpp
// Date: 2025-09-10
// By Breno Cunha Queiroz
//--------------------------------------------------
#include <drivers/encoder/encoder.h>
#include <drivers/hardware.h>
#include <utils/log.h>

bool Encoder::init(Spi::Peripheral peripheral, Gpio::Gpio chipSelect) {
    _peripheral = peripheral;
    _chipSelect = chipSelect;
    Gpio::write(_chipSelect, true);

    // Initial NOP to initialize SPI (first transaction often fails and triggers the encoder's error flag)
    uint16_t nop_cmd = createCommandFrame(REG_NOP, false);
    transmitReceive(nop_cmd);

    // Verify communication by reading a known register
    if (!verifyCommunication()) {
        Log::error("Encoder", "Failed to initialize");
        return false;
    }

    Log::success("Encoder", "Initialized");
    return true;
}

std::optional<float> Encoder::readAngle() {
    auto response = readRegister(REG_ANGLE);
    if (!response)
        return std::nullopt;

    // Convert the raw 14-bit angle (0-16383) to degrees
    return (response->fields.data / 16383.0f) * 360.0f;
}

std::optional<uint16_t> Encoder::readMagnitude() {
    auto response = readRegister(REG_MAGNITUDE);
    if (!response)
        return std::nullopt;
    return uint16_t(response->fields.data);
}

bool Encoder::verifyCommunication() {
    // Reading any register successfully is a good verification.
    // We read the diagnostics register as it should always return a valid value.
    auto response = readRegister(REG_CLEAR_ERROR);
    return response.has_value();
}

std::optional<Encoder::ReadFrame> Encoder::readRegister(Reg address) {
    // 1. Create the command frame for the target register.
    uint16_t read_cmd = createCommandFrame(address, true);
    // 2. Create a NOP command to clock out the response.
    uint16_t nop_cmd = createCommandFrame(REG_NOP, false);

    // 3. Send the read command (response is discarded), then send a NOP to get the actual response.
    transmitReceive(read_cmd);
    auto raw_response = transmitReceive(nop_cmd);

    if (!raw_response) {
        Log::error("Encoder", "SPI communication failed at HAL level.");
        return std::nullopt;
    }

    // 4. Parse the received frame to validate it.
    ReadFrame response = parseReadFrame(*raw_response);

    // 5. Check for sensor-level errors (bad parity or error flag set).
    if (!response.parityOK || response.fields.errorFlag) {
        Log::warning("Encoder", "Received frame with error. Parity OK: $0, Error Flag: $1", response.parityOK, uint16_t(response.fields.errorFlag));
        return std::nullopt;
    }

    return response;
}

std::optional<uint16_t> Encoder::transmitReceive(uint16_t txData) {
    uint16_t rxData = 0;

    Gpio::write(_chipSelect, false); // CS Low
    bool success = Spi::transmitReceive(_peripheral, reinterpret_cast<uint8_t*>(&txData), reinterpret_cast<uint8_t*>(&rxData), 1);
    Gpio::write(_chipSelect, true); // CS High
    Hardware::delayMs(1);           // Short delay to ensure sensor is ready

    if (!success)
        return std::nullopt;

    // Swap the bytes of the received data back to the correct order for the CPU.
    return rxData;
}

Encoder::ReadFrame Encoder::parseReadFrame(uint16_t rawFrame) {
    ReadFrame frame;
    frame.parityOK = validateReceivedParity(rawFrame);
    frame.fields.errorFlag = (rawFrame >> 14) & 0x01;
    frame.fields.data = rawFrame & 0x3FFF;
    return frame;
}

uint16_t Encoder::createCommandFrame(Reg address, bool isRead) {
    uint16_t command = address & 0x3FFF;
    if (isRead) {
        command |= (1 << 14); // Set the read/write bit (RWn)
    }
    if (calculateParityBit(command)) {
        command |= (1 << 15); // Set the parity bit (PAR)
    }
    return command;
}

bool Encoder::validateReceivedParity(uint16_t rawFrame) {
    uint8_t count = 0;
    for (int i = 0; i < 16; i++) {
        if ((rawFrame >> i) & 0x01) {
            count++;
        }
    }
    // For a valid even parity frame, the total number of set bits must be even.
    return (count % 2) == 0;
}

uint8_t Encoder::calculateParityBit(uint16_t value) {
    uint8_t count = 0;
    for (int i = 0; i < 15; i++) {
        if ((value >> i) & 0x01) {
            count++;
        }
    }
    // For even parity, the parity bit is 1 if the number of set bits is odd.
    return (count % 2);
}

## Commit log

2023-09-07 Feat: STM32 HAL
    [stlink-dap.cfg, stm32f4.cfg]
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2023-09-07 Feat: Starting GPIO driver
2023-09-08 Feat: Starting USB driver
2023-09-08 Feat: GDB working
    [stlink-dap.cfg, stm32f4.cfg]
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2023-09-14 Feat: Encoder CRC check
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2023-09-21 Test: Motor driver rotation
2023-09-23 Feat: Starting atta connector
2023-09-27 Feat: Starting BLDC simulation
2023-09-28 Feat: Show motor orientation in 3D
2023-10-01 Feat: Atta connector CRC
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2023-10-05 Fix: Atta connector not all packets received
    [attaConnectorPlatform.cpp, main.cpp]
2023-10-07 Fix: Atta connector ACK/NACK
    [main.cpp]
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2023-11-23 Fix: Clock with 24MHz crystal
    [clock.cpp, log.cpp, main.cpp]
2023-11-23 Fix: USART6 not working
    [main.cpp]
2023-11-23 Fix: Atta connector with STLINK
    [log.cpp, main.cpp]
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2023-11-30 Fix: Wrong SPI initialization
    [imu.h]
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2025-04-09 Feat: Setup KiCad project
    [BLDCM.kicad_pcb, BLDCM.kicad_sch]
2025-05-06 Feat: KiCad BLDCM-MCU schematic
    [BLDCM-MCU.kicad_pcb, BLDCM-MCU.kicad_sch, BLDCM.kicad_pcb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]
2025-05-06 Feat: KiCad BLDCM-Power schematic
    [BLDCM-Power.kicad_pcb, BLDCM-Power.kicad_sch]
2025-05-06 Fix: BLDCM-Power ERC errors
    [BLDCM-Power.kicad_sch]
2025-05-06 Fix: BLDCM-MCU ERC errors
    [BLDCM-MCU.kicad_sch]
2025-05-06 Fix: PCB resistor rotation
    [BLDCM-MCU.kicad_pcb, BLDCM-Power.kicad_pcb]
2025-05-06 Chore: Rename electrical to electronics
    [BLDCM-MCU.kicad_pcb, BLDCM-MCU.kicad_sch, BLDCM-Power.kicad_pcb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]
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2025-05-12 Feat: Finish MCU PCB routing
    [BLDCM-MCU.kicad_pcb]
2025-05-12 Feat: Initial FreeCAD files
    [BLDCM.FCStd, BLDCM_PCB_MCU.FCStd, BLDCM_PCB_Power.FCStd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]
2025-05-12 Refactor: Power PCB resistor
    [BLDCM-Power.kicad_pcb]
2025-05-12 Chore: Configure Git LFS
    [BLDCM.FCStd, BLDCM_PCB_MCU.FCStd, BLDCM_PCB_Power.FCStd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]
2025-05-30 Feat: MCU schematic add VIN note
    [BLDCM-MCU.kicad_pcb, BLDCM-MCU.kicad_sch]
2025-05-30 Feat: Power PCB replace symbols with brenocq lib symbols
    [BLDCM-Power.kicad_pcb, BLDCM-Power.kicad_sch]
2025-05-31 Refactor(mechanical): Divide motor into rotor and stator
    [Motor_EM3215.FCStd]
2025-05-31 Feat(mechanical): Screw M1.6 T5 5mm countersink
    [Screw_CS_5MM.FCStd]
2025-05-31 Feat(mechanical): Rotor adapter
    [Rotor_Adapter.FCStd]
2025-05-31 Feat(mechanical): Update motor and rotor adapter in assembly
    [BLDCM.FCStd]
2025-05-31 Feat(mechanical): Add rotor adapter heat-set insert
    [BLDCM.FCStd, HeatSet_M1.6_3MM.FCStd]
2025-05-31 Feat(mechanical): Test heat-set insert hole
    [Test_HeatSet_Hole.FCStd]
2025-05-31 Refactor(mechanical): Rotor adapter heat-set insert chamfer
    [BLDCM.FCStd, Motor_EM3215.FCStd, Rotor_Adapter.FCStd]
2025-05-31 Feat(mechanical): Chassis motor enclosure
    [BLDCM.FCStd, BLDCM_Chassis.FCStd, BLDCM_Rotor_Adapter.FCStd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]
2025-05-31 Feat(mechanical): Screw pan head M1.6 8mm
    [BLDCM.FCStd, BLDCM_Chassis.FCStd, Screw_CS_5MM.FCStd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]
2025-05-31 Feat(mechanical): Chassis top enclosure
    [BLDCM.FCStd, BLDCM_Chassis.FCStd]
2025-05-31 Feat: Attach MCU PCB to motor
    [BLDCM-MCU.kicad_pcb, BLDCM.FCStd, BLDCM_Chassis.FCStd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]
2025-06-02 Feat(pcb): Create net classes in power PCB
    [BLDCM-Power.kicad_pcb, BLDCM-Power.kicad_sch]
2025-06-02 Feat(pcb): Route differential pairs in Power PCB
    [BLDCM-Power.kicad_pcb, BLDCM-Power.kicad_sch]
2025-06-03 Feat(pcb): Fix DRC for Power PCB
    [BLDCM-Power.kicad_pcb]
2025-06-03 Feat(pcb): Add power management sheet
    [BLDCM-Power.kicad_sch, PowerManagement.kicad_sch]
2025-06-27 Fix(pcb): Add missing USB CC1 pull-down
    [BLDCM-Power.kicad_sch, PowerManagement.kicad_sch]
2025-06-27 Refactor(pcb): Rename VIN to 5V in MCU PCB
    [BLDCM-MCU.kicad_pcb, BLDCM-MCU.kicad_sch]
2025-06-29 Feat(schematic): Automatic power source selection
    [BLDCM-Power.kicad_pcb, BLDCM-Power.kicad_sch, PowerManagement.kicad_sch]
2025-06-30 Feat(schematic): Update volt sense to use BAT54S
    [BLDCM-Power.kicad_pcb, BLDCM-Power.kicad_sch, PowerManagement.kicad_sch]
2025-07-02 Feat(schematic): Use STM32 ADCs for phases curr/volt
    [BLDCM-MCU.kicad_sch]
2025-07-04 Feat(schematic): Replace current sense resistors
    [BLDCM-Power.kicad_sch, PowerManagement.kicad_sch]
2025-07-04 Feat(schematic): Replace INA239 with INA240
    [BLDCM-Power.kicad_pcb, BLDCM-Power.kicad_sch]
2025-07-05 Feat(schematic): High frequency voltage sense
    [BLDCM-Power.kicad_pcb, BLDCM-Power.kicad_sch]
2025-07-05 Fix(schematic): Power board ERC errors
    [BLDCM-Power.kicad_sch, PowerManagement.kicad_sch]
2025-07-13 Feat(pcb): Route phase voltage sense
    [BLDCM-Power.kicad_pcb, BLDCM-Power.kicad_sch]
2025-07-13 Feat(pcb): Route power management
    [BLDCM-Power.kicad_pcb, PowerManagement.kicad_sch]
2025-07-13 Feat(pcb): Route motor phases
    [BLDCM-Power.kicad_pcb]
2025-07-14 Feat(pcb): Route volt/curr sense
    [BLDCM-Power.kicad_pcb]
2025-07-14 Fix(pcb): DRC errors
    [BLDCM-Power.kicad_pcb]
2025-07-14 Refactor(pcb): Update footprints
    [BLDCM-Power.kicad_pcb, BLDCM-Power.kicad_sch, PowerManagement.kicad_sch]
2025-07-14 Feat(pcb): Replace USB with Molex USB
    [BLDCM-Power.kicad_pcb, BLDCM-Power.kicad_sch]
2025-07-15 Refactor(schematic): Rename INA nets to CURR
    [BLDCM-Power.kicad_pcb, BLDCM-Power.kicad_sch]
2025-07-15 Feat(pcb): Route current sense
    [BLDCM-MCU.kicad_pcb, BLDCM-MCU.kicad_sch]
2025-07-15 Feat(pcb): Initial MCU PCB routing
    [BLDCM-MCU.kicad_pcb]
2025-07-15 Fix(pcb): MCU PCB DRC errors
    [BLDCM-MCU.kicad_pcb]
2025-07-18 Feat: v1.0 MCU/Power PCBs ready
    [BLDCM-MCU.kicad_pcb, BLDCM-MCU.kicad_sch, BLDCM-Power.kicad_pcb]
2025-07-19 Feat: PCB adjustments for manufacturing
    [BLDCM-MCU.kicad_pcb, BLDCM-Power.kicad_pcb]
2025-07-19 Feat: Add schematic PDFs for v1.0 PCBs
    [BLDCM-MCU.kicad_sch, BLDCM-Power.kicad_sch, PowerManagement.kicad_sch]
2025-07-20 Feat: Populate PCB page footer
    [BLDCM-MCU.kicad_pcb, BLDCM-Power.kicad_pcb]
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2025-07-20 Refactor(pcb): Update stackup colors
    [BLDCM-MCU.kicad_pcb, BLDCM-Power.kicad_pcb]
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2025-07-20 Feat: Setup KiCad project specific libraries
    [BLDCM-MCU.kicad_pcb, BLDCM-MCU.kicad_sch, BLDCM-Power.kicad_pcb]
2025-07-20 Fix: PCB 3D model references
    [BLDCM-MCU.kicad_pcb, BLDCM-MCU.kicad_sch, BLDCM-Power.kicad_pcb]
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2025-08-16 Feat(fw): PCB v1.0 heartbeat
    [BLDCM.FCStd, BLDCM_Chassis.FCStd, BLDCM_PCB_MCU.FCStd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]
2025-08-30 Fix(fw): UART DMA transmission
    [clock.cpp, dma.cpp, gpio.cpp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]
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2025-09-01 Feat(fw): Add prescaler and datasize options to SPI config
2025-09-01 Fix(fw): IMU initialization
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2025-09-11 Style(schematic): Add USART6 to text box
    [BLDCM-MCU.kicad_sch]
2025-09-11 Refactor(mechanical): Remove center of mass from screw
    [Screw_CS_5MM.FCStd]
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
